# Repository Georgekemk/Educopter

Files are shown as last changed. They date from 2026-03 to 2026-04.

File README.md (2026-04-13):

<h1 align="center">EDUCOPTER</h1>

<p align="center">
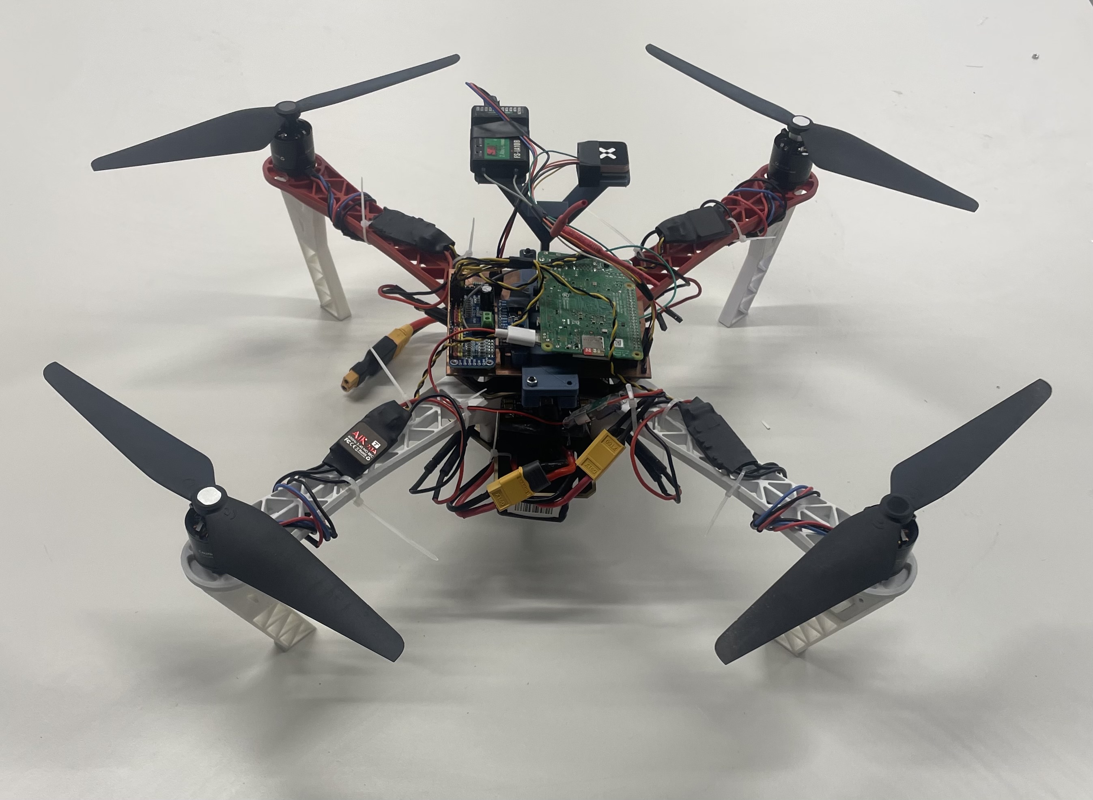
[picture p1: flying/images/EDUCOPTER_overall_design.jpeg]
  
</p>

Welcome to the **EDUCOPTER GitHub repository**.

This project has been developed based on the work of the **OBAL project**, which demonstrated that a Raspberry Pi can be used as the single flight computer for a custom ArduPilot flight controller. Thanks go to **Mohammad Hefny** for his contribution to custom Linux flight controller developement.

EDUCOPTER builds upon this foundation with the goal of creating a **simpler, highly replicable custom flight controller designed specifically for education and experimentation**.

---

# What is EDUCOPTER?

**EDUCOPTER** is a **minimal ArduPilot-compatible flight controller platform** designed to be easily reproduced by students, researchers, and hobbyists. Although this repository demonstrates its use on a quadcopter, the EDUCOPTER board can be used with any vehicle supported by ArduPilot, including rovers, fixed-wing aircraft, submarines, and multirotors.

Unlike many flight controller designs that prioritise performance or compactness, EDUCOPTER prioritises **simplicity and reproducibility**.

Key characteristics of the design include:

* A **Raspberry Pi–based Linux flight controller**
* A **single-sided PCB** for easy manufacturing
* Only **essential sensors and actuators** required to fly with ArduPilot
* ArduPilot source code changes for Linux porting
* Parameter and Service files to run alonside ArduPilot and MAVProxy
* A complete set of **documentation and instructions** allowing others to replicate the project from scratch with little experience in this area

The project demonstrates how a fully functional ArduPilot drone can be built with **minimal hardware complexity**, while still providing a powerful and flexible autopilot platform.

---

# Project Goals

The EDUCOPTER project aims to:

* Provide a **simple reference design** for a Linux-based ArduPilot drone
* Enable **students and educators** to build and understand a flight controller
* Demonstrate how **ArduPilot can run on custom hardware**
* Provide **clear instructions and documentation** for full system replication
* Present a guide for porting any custom Linux board design in ArduPilot firmware

---

# Repository Structure

This repository is organised into several sections to make it easy to understand and reproduce the project.

```
EDUCOPTER/
├── software/
├── hardware/
├── BOM/
├── flying/
├── testing/
├── Future Research/
```

Each section contains documentation and files required for a specific stage of the project. The future research section summarises the Linux board specific porting for ArduPilot, and gives some examples of future projects that can build from the EDUCOPTER platform.

---

# Software

The **software** section contains all code and configuration required to run ArduPilot on the EDUCOPTER flight controller.

This includes:

* Modified or configured ArduPilot code
* Supporting scripts and configuration files
* Instructions for installing and running the software on the Raspberry Pi

A detailed README inside this folder contains instructions for software implementation and **must be read**. It explains:

* Raspberry Pi setup and connection
* Linux Virtual Environment setup
* Compiling ArduPilot
* Configuring the EDUCOPTER board
* Connecting to ground control software
* Running the firmware and testing

```
software/
└── README.md
```

---

# Hardware

The **hardware** section explains how to construct the EDUCOPTER flight controller board.

This includes:

* PCB gerber files and images
* Circuit schematics
* Instructions for manufacturing the board
* Guidance for soldering components and assembling the hardware

The hardware README provides **step-by-step instructions** for building the EDUCOPTER board.

```
hardware/
└── README.md
```

---

# Bill of Materials (BOM)

The **BOM section** contains a complete list of components required to build both the EDUCOPTER flight controller and the final drone platform.

This includes:

* Electronic components used on the board
* Sensors and connectors
* External drone components such as motors, ESCs, frame, and power distribution board

These parts are included primarily for completeness; compatible alternatives may be used where appropriate.

```
BOM/
└── BOM.xlsx
```

---

## Testing the flight controller

The testing section documents the procedures used to verify correct operation of the EDUCOPTER flight controller before flight.

This section contains:

* Instructions for confirming SPI communication with the IMU
* Instructions for verifying I2C device detection for the barometer and PWM driver
* Instructions for testing UART connections for the GPS module and RC receiver

```
testing/
└── README.md
```
---

# Flying the Drone

The **flying** section demonstrates the final stage of the project.

This section contains:

* Images of the completed drone
* Instructions for integrating the EDUCOPTER board with a quadcopter design
* Instructions for performing the first flight

```
flying/
└── README.md
```

---

## Future Research

The future section then outlines possible extensions to the EDUCOPTER platform and identifies directions for further experimentation based on this architecture.

```
Future Research/
└── README.md
```

---

# Replicating the Project

This repository has been structured so that users can **follow the entire process from start to finish**, including:

1. Building the flight controller hardware
2. Installing and configuring the software
3. Assembling the drone platform
4. Performing system calibration and first flight

All necessary documentation is provided within the repository.

---

# Acknowledgements

This project builds upon the work of the **OBAL project** and the wider **ArduPilot community**.

Special thanks to **Mohammad Hefny** for his contributions to the OBAL platform and for enabling Linux-based flight controller development.

Also thanks go to **Oliver Vogt** for his supervision and guidance with this project.

---

# License

This project follows the licensing terms of the software and tools it builds upon. Please refer to the relevant directories for detailed licensing information.

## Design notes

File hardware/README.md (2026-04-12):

# EDUCOPTER Hardware Setup

This guide explains how to construct and assemble the **EDUCOPTER flight controller hardware**.  
It covers sensor connections, PCB manufacturing, soldering components, connecting peripherals, and powering the system.

The EDUCOPTER board has been intentionally designed to be **simple to manufacture and assemble**, using a **single-sided PCB** and only the sensors required for ArduPilot operation.

---

# 1. Sensor and Peripheral Connections

The EDUCOPTER board uses standard interfaces supported by **ArduPilot on Linux-based flight controllers**. Wherever possible, commonly used pin assignments have been used so that ArduPilot can detect and initialise sensors without extensive configuration.

A summary of hardware components and their communication methods is shown below. The black arrows represent physical connection on the PCB and the pink arrows represent connection via network port.

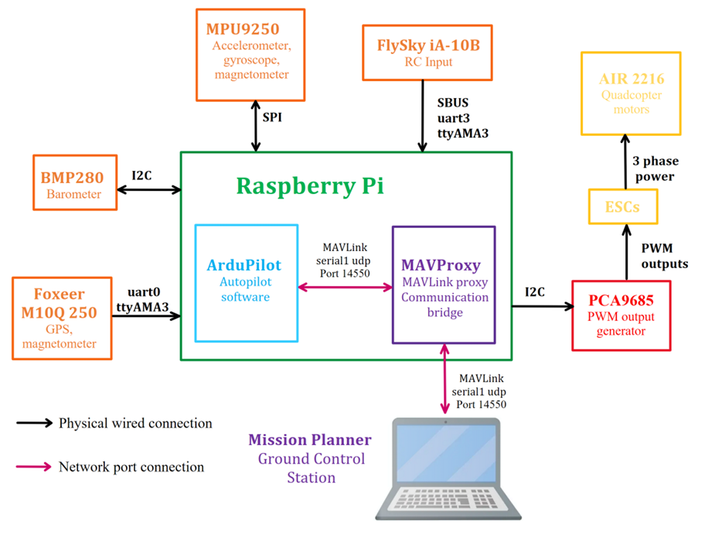
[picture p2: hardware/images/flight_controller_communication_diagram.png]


### Sensor Interface Overview

| Device | Interface | Purpose |
|---|---|---|
| IMU (MPU9250) | SPI | Attitude estimation (gyro + accelerometer) |
| Barometer | I2C | Altitude estimation |
| PCA9685 PWM driver | I2C | Motor PWM outputs |
| GPS module | UART | Position and velocity |
| RC Receiver (SBUS) | UART | Remote control input |

---

### SPI – IMU

The **IMU** is connected using the SPI interface. SPI provides fast and reliable communication required for inertial measurements.

SPI pins include:

- MOSI  
- MISO  
- SCLK  
- CS (chip select)

These are connected to the Raspberry Pi SPI bus using standard Linux ArduPilot mappings.

---

### I2C – Barometer BMP280 and PCA9685

Both the **barometer** and the **PCA9685 PWM driver** are connected using the **I2C bus**.

Advantages of I2C:

- Multiple devices share the same bus  
- Only two signal wires are required

---

### UART – GPS

The GPS module communicates using **UART serial communication**.

| GPS Pin | Connects To |
|---|---|
| TX | Raspberry Pi RX |
| RX | Raspberry Pi TX |
| VCC | 5V |
| GND | Ground |

**Important:**  
GPS **TX must connect to Pi RX**, and **GPS RX must connect to Pi TX**.

---

### UART – SBUS Receiver

The RC receiver uses the **SBUS protocol**, which transmits multiple RC channels over a serial connection.

SBUS can be used on many GPIO pins, but the configuration used in EDUCOPTER is UART0, using pins GPIO14 and 15.

Before use, the UART must be **enabled on the Raspberry Pi**.

The circuit schematic is shown below.

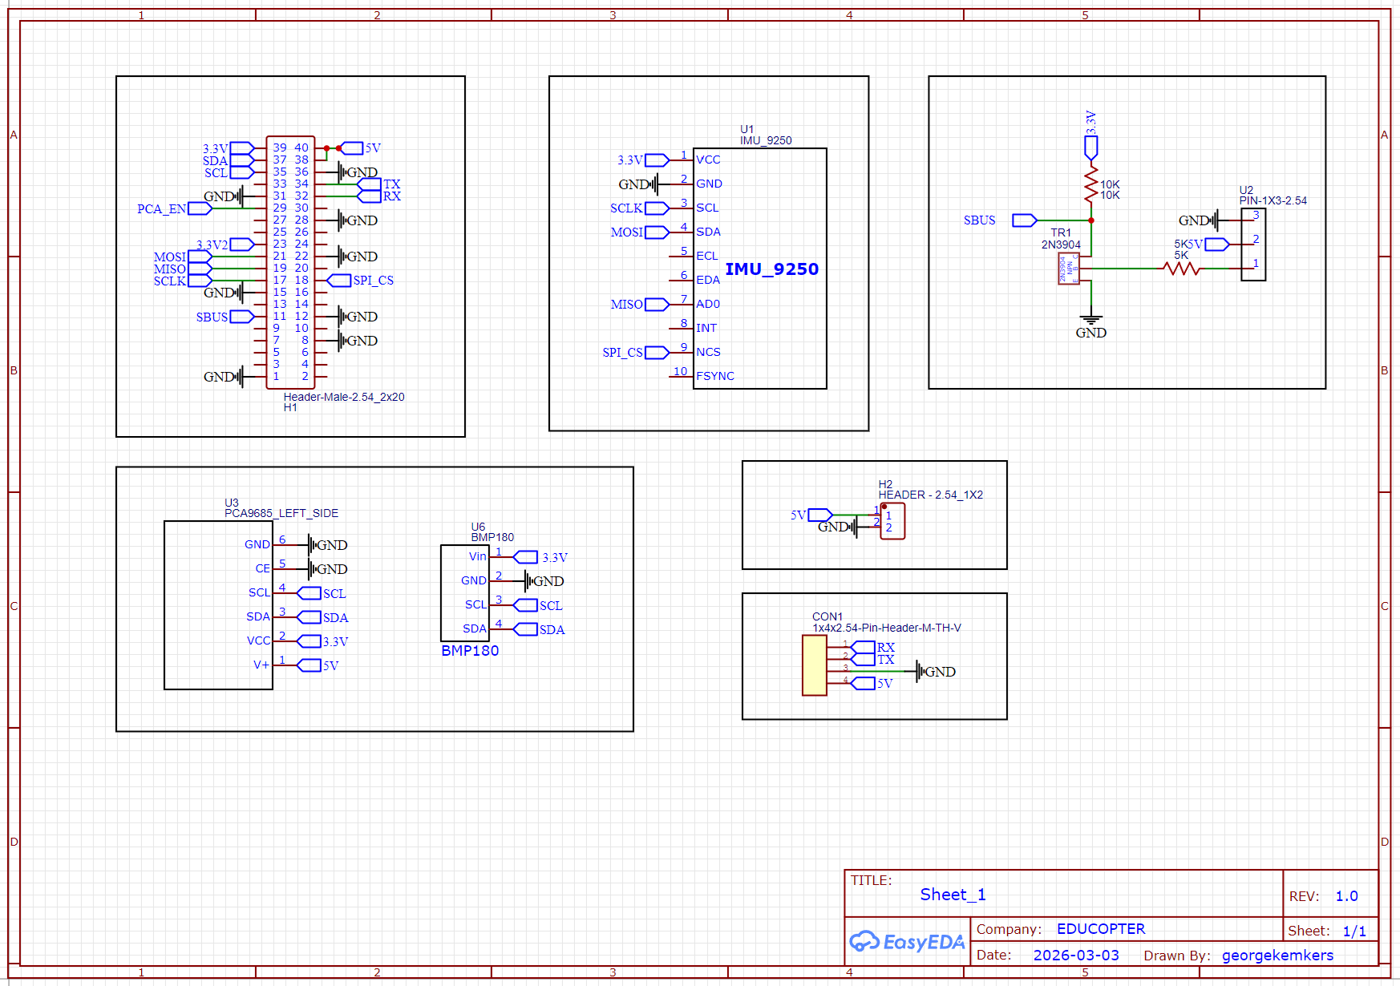
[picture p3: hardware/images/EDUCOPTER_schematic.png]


---

# 2. Build the SBUS Inversion Circuit

SBUS signals are **inverted**, whereas the Raspberry Pi UART expects **non-inverted serial data**.

To correct this, a **simple transistor inverter circuit** is used.

### Required Components

| Component | Value |
|---|---|
| NPN transistor | 2N3904 |
| Base resistor | 5 kΩ |
| Pull-up resistor | 10 kΩ |

### Circuit Operation

- SBUS signal enters the **base resistor**
- The transistor switches the signal
- The collector outputs a **non-inverted UART signal**
- The pull-up resistor ensures correct logic levels

This can be seen in the schematic in the box titled 'SBUS Inverter Circuit on UART3'

---

# 3. Manufacture the PCB

The EDUCOPTER PCB is designed to be **single sided**, making it suitable for **PCB milling machines**.

Advantages:

- Easier fabrication
- No vias required
- Suitable for educational environments

### PCB Structure

Two Gerber layers are used:

1. **Bottom copper layer (traces)**
2. **Top insulation layer**

All **traces and solder joints are on the bottom side** of the board, and the top side only electrically insulates the pins in case they touch the copper surface.

### Gerber Files

The gerber files are included in the hardware section of this repository.

---

### PCB Milling

The board used in this project was manufactured using a **Makera Carvera PCB milling machine**.

A **Standard Operating Procedure (SOP)** for using the Carvera can be found on Makera's website or youtube channel.

---

# 4. Solder the Components

Once the PCB has been manufactured, components must be soldered onto the board.

The EDUCOPTER PCB was designed with **approximately 0.35 mm trace spacing**, making it relatively managable for novice solderers.

### Required Tools

- Soldering iron  
- Solder  
- Tweezers  
- Flux (recommended)

All components should be soldered to the pads on the backside of the board, shown in the image below:

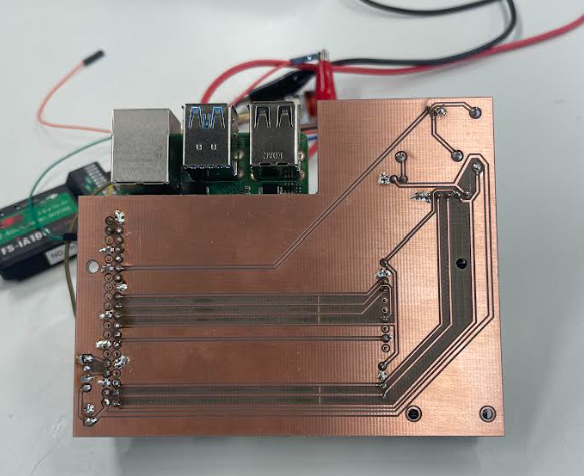
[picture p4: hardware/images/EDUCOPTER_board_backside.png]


---

# 5. Connect the RC Receiver and GPS

External peripherals connect via header pins.

---

### RC Receiver Connection

| Receiver Pin | Connect To |
|---|---|
| SBUS | SBUS input |
| 5V | 5V |
| GND | Ground |

The SBUS signal must pass through the **inversion circuit** before reaching the Pi UART.

---

### GPS Wiring

Correct wiring is essential.

| GPS Pin | Connect To |
|---|---|
| TX | Pi RX |
| RX | Pi TX |
| VCC | 5V |
| GND | Ground |

---

# 6. Power the Circuit

The EDUCOPTER board can be powered in two ways.

---

### Method 1 – PCB Power Pins

The board includes **dedicated 5V input pins**, shown in the 5V 3A Power input box in the circuit schematic.

Connect these to a 5V DC power supply from a regulated power source.

### Method 2 – Raspberry Pi USB-C

The board can also be powered using the Raspberry Pi **USB-C power input**, which is the primary method used for this design. A DC--DC buck converter with a usbc connector on the end is included in the BOM, and details of how to connect this are included in the 'flying' section of this repository.

---

# 7. Final Hardware Checklist

Before powering the board:

✔ Check for solder bridges  
✔ Confirm correct sensor orientation   
✔ Ensure GPS TX/RX wiring is correct  
✔ Confirm correct power polarity  

The completed board is with the GPS and RC receiver units connected is shown below:

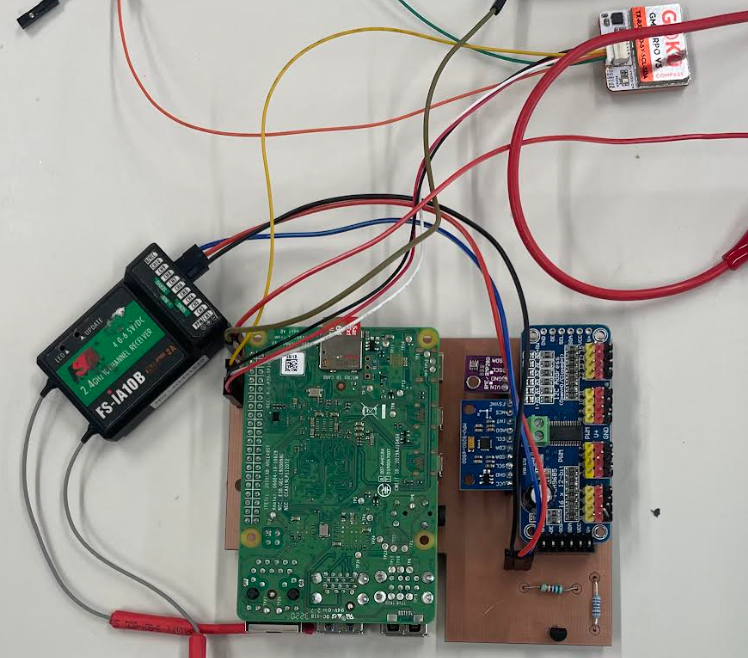
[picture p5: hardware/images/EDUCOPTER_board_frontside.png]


---

# Next Step

Once the hardware is assembled and verified, proceed to the **software setup instructions**:

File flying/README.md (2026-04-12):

# Assembling the EDUCOPTER Quadcopter

With the EDUCOPTER board successfully built and the EDUCOPTER binary installed along with MAVProxy and the system service files created, you're now ready to build the drone. Ensure the Raspberry Pi is connected to the EDUCOPTER board and follow these steps in order.

## 1. Installing the Holybro Power Distribution Board

Place the **Holybro PM07 power distribution board** inside the drone frame base plate.

Plug the four ESC power leads into the ports of the Holybro board.

Ensure:

- polarity is correct
- connections are secure
- cables are not under tension
- space is left above the board for mounting the EDUCOPTER controller

Insert image here

---

## 2. Mounting the EDUCOPTER Flight Controller

Fix the EDUCOPTER board to the top of the drone frame using a **3D printed mounting structure** designed for your frame geometry.

An example mounting structure is shown below.

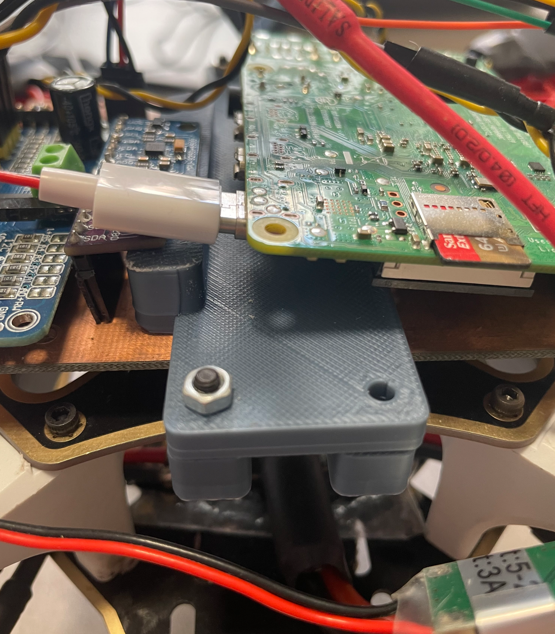
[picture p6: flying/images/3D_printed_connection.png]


Ensure:

- the board is rigidly mounted
- the IMU is firmly secured and can't wobble or vibrate
- the Raspberry Pi USB-C port remains accessible

Loose IMU mounting will cause incorrect attitude estimation during flight and control issues.

---

## 3. Connecting the GPS and RC Receiver

Connect the GPS module and RC receiver to the EDUCOPTER board.

Connections:

- GPS → 4 pin header with 5V, GND, RX, TX
- SBUS receiver → 3 pin header with GND, 5V, SBUS

Ensure that the cables connect to the correct corresponding pins by referring to the circuit schematic and gerber files. The GPS RX must connect to the Pi TX pin, and the GPS TX to the Pi RX.

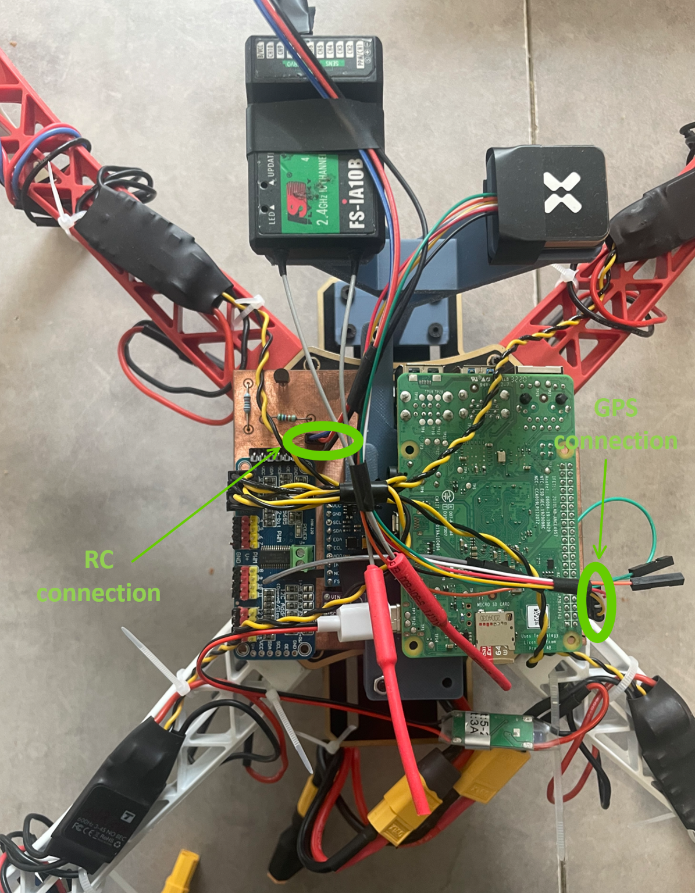
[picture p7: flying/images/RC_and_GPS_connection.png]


Use a structure to elevate the GPS and RC receiver above the board to minimise inteference to the GPS from power components and to increase the range of the receiver.

---

## 4. Connecting ESC Signal Outputs to the PCA9685

Attach the ESC signal wires to the signal and ground pins of the PCA9685.

ESC numbering follows the PCA9685 channel order from left to right:

- ESC 1 → Channel 0
- ESC 2 → Channel 1
- ESC 3 → Channel 2
- ESC 4 → Channel 3

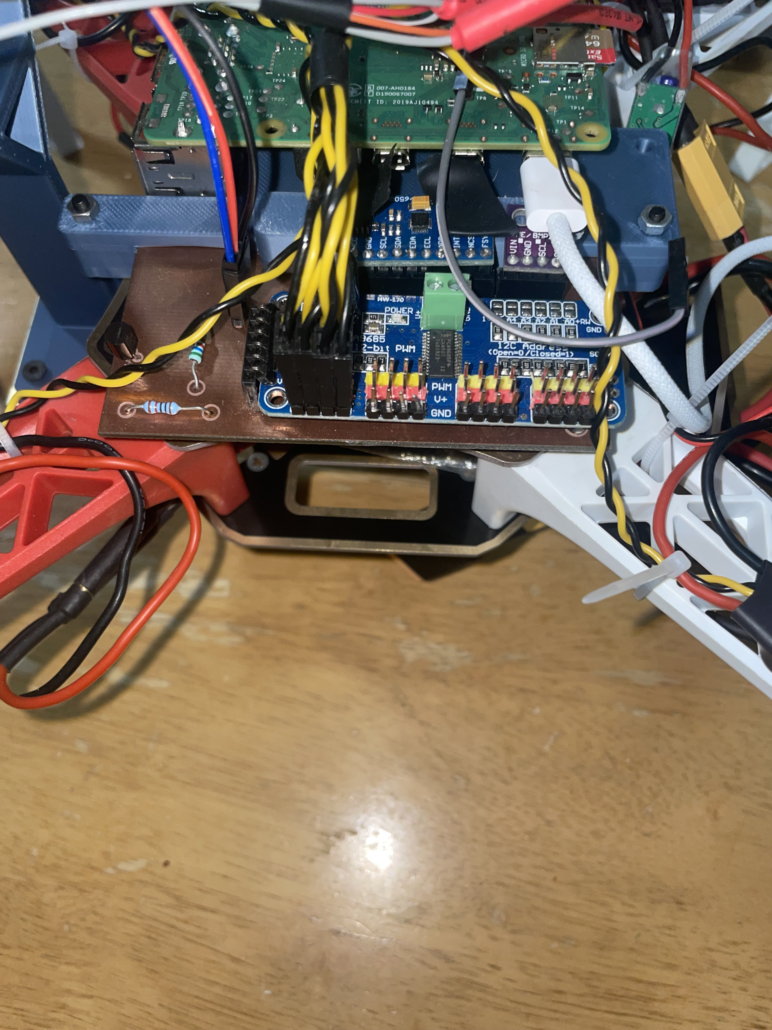
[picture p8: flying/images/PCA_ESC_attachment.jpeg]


The **QUAD-X motor configuration must be followed**.

Incorrect ordering will prevent stable flight.

---

## 5. Mounting the Motors

Attach the motors to the drone frame arms using the supplied nuts and bolts.

Once mounted, connect each motor to its ESC.

Do not attach propellers yet.

Motor rotation direction will be verified later during calibration.

---

## 6. Installing the Battery and Power Connections

Attach the battery to the underside of the drone frame. It is recommended to do this using a velcro mechanism so batteries can be easily substituted if needed, but any connect will suffice.

Connect the power splitter to the battery output, and connect the USBC to the Pi and the other connector to the power distribution board. 

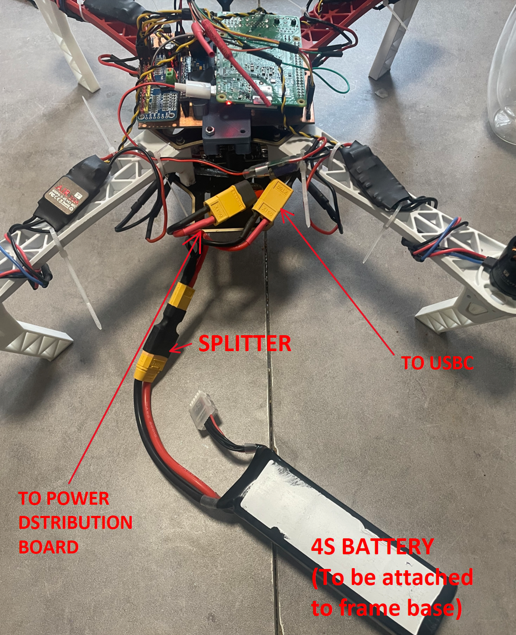
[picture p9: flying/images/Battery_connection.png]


The Pi should power on, the PCA will hold a solid red light and the GPS and RC receiver should light up. It is recommended at this point to ssh to the Pi so that it can be easily shutdown if errors occur.

---

## 7. Performing ArduPilot Calibration

Once assembly is complete, calibration can begin using Mission Planner.

Complete the following calibrations:

- accelerometer calibration
- compass calibration
- RC calibration

This can be done in the setup section of Mission Planner, where detailed instructions are located.

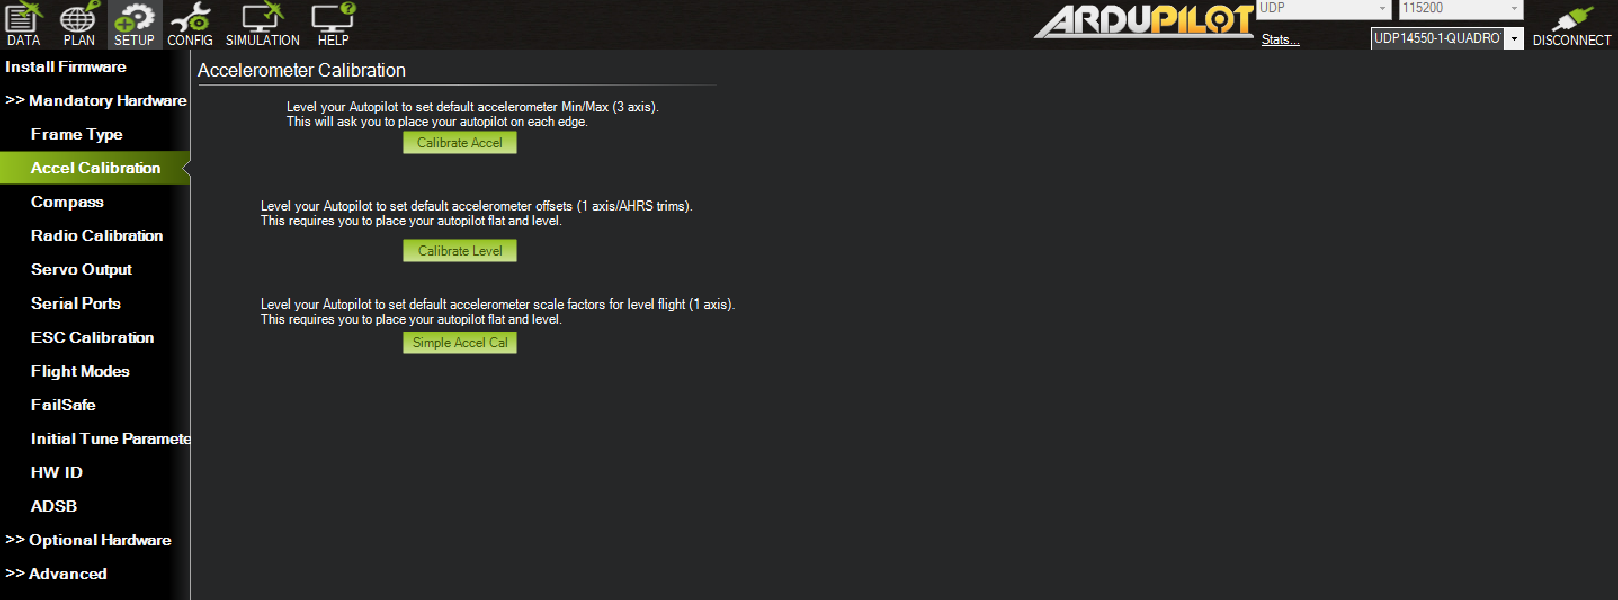
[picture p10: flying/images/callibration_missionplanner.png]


ESC calibration depends on ESC type. The standard ArduPilot ESC calibration process works for most ESCs but should be checked against manufacturer documentation before use.

---

## 8. Testing RC Outputs Before Flight

Ensure propellers are **not attached** before testing.

Arm the throttle using either:

the MAVProxy command

arm throttle

or by holding the RC throttle hard left for several seconds.

Test outputs by adjusting:

- throttle
- yaw
- pitch
- roll

Observe PWM outputs from the PCA9685 channels

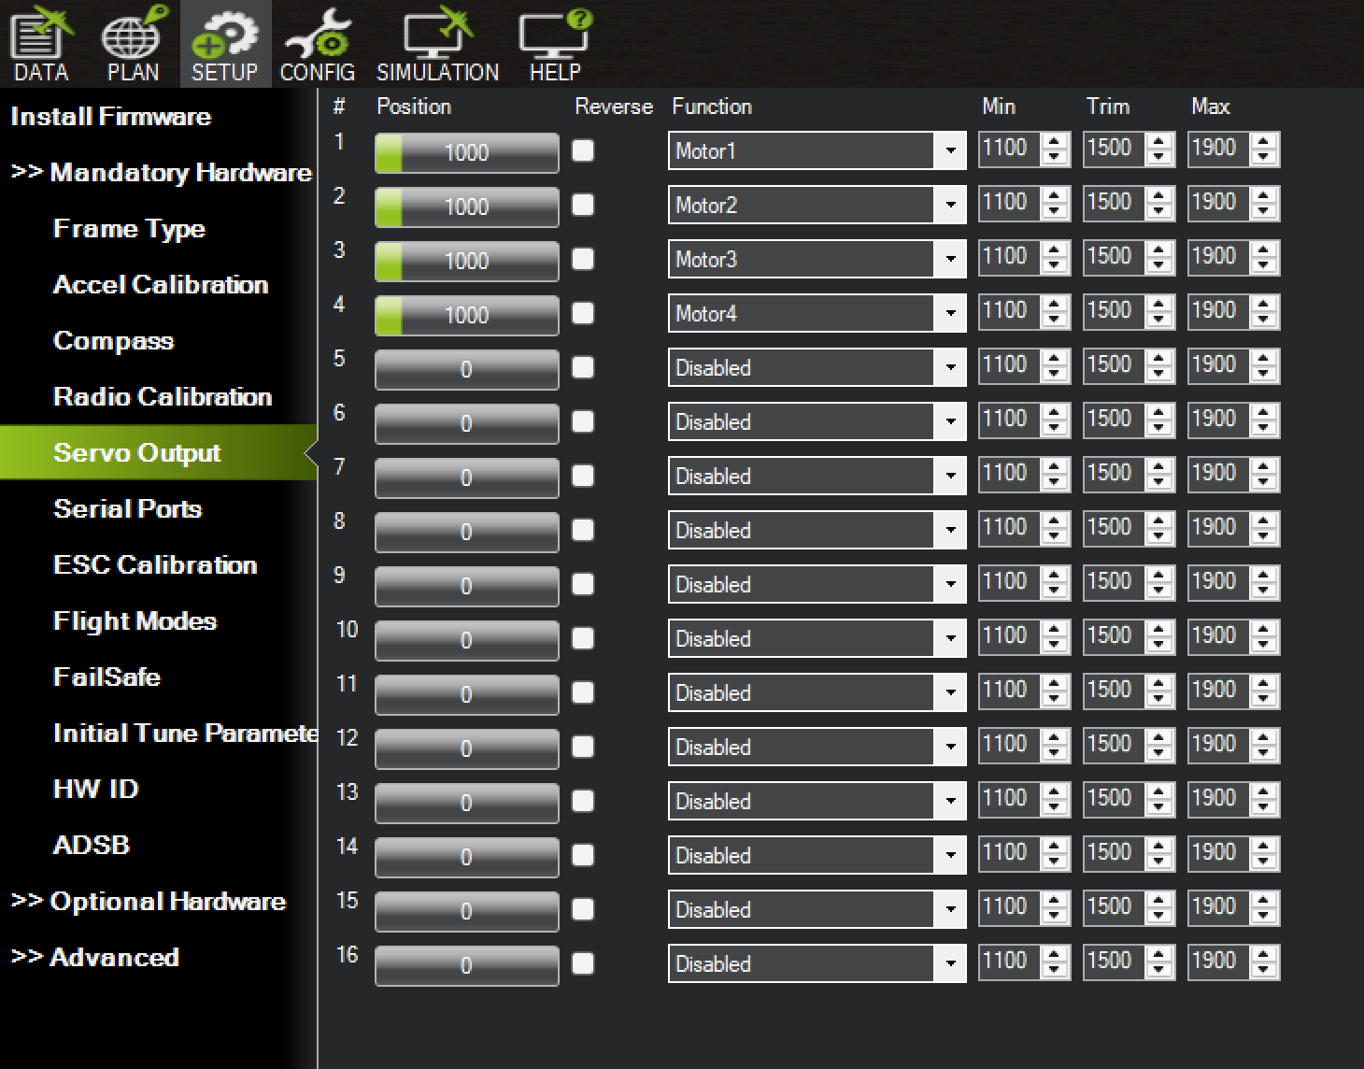
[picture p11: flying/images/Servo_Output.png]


---

## 9. Verifying Motor Rotation Direction

Using telemetry dash board in Mission Planner, tilt the drone in the x and y direction until the pitch changes. This can be used to find the forward direction of the drone. Alternatively, rotate the drone until the yaw reads 0 degrees. The front of the drone will now be facing North.

This will help to determine the correct motor rotation directions.

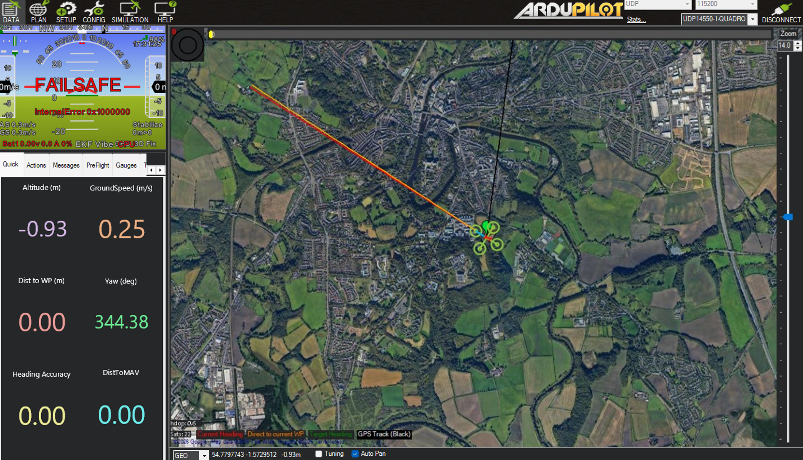
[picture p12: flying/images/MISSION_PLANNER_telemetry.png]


Use the Mission Planner motor test function to confirm correct motor rotation.

Expected QUAD-X rotation directions:

- front right → clockwise
- front left → counter-clockwise
- rear left → clockwise
- rear right → counter-clockwise

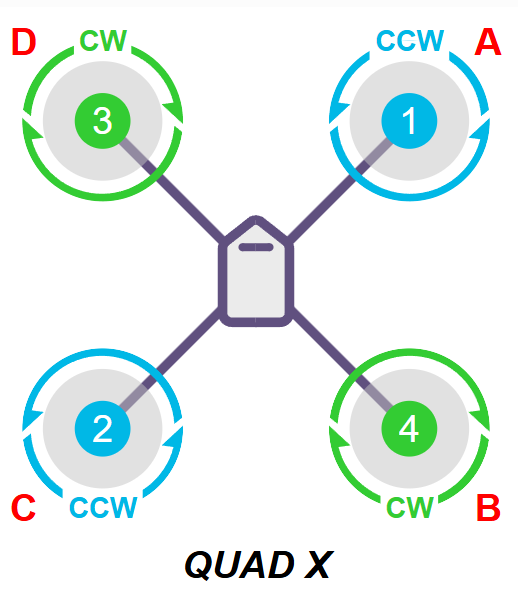
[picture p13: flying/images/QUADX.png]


If rotation is incorrect, swap any two ESC-motor wires.

---

## 10. First Flight

Once calibration and testing are complete, attach the propellers.

Move to an open outdoor space before attempting flight.

Before take-off confirm:

- battery secure
- GPS lock achieved
- transmitter connected
- failsafe configured
- correct flight mode selected

Set the initial flight mode to:

STABILIZE

Ensure compliance with local drone regulations before flying.

Happy flying!

## 11. Flight Results

Data from the flights was stored in a log file, the directory for which has already been assigned using **ardupilot.parm**.

The logs files from two seperate 30s flights were processed, and the plotted graphs are shown below:

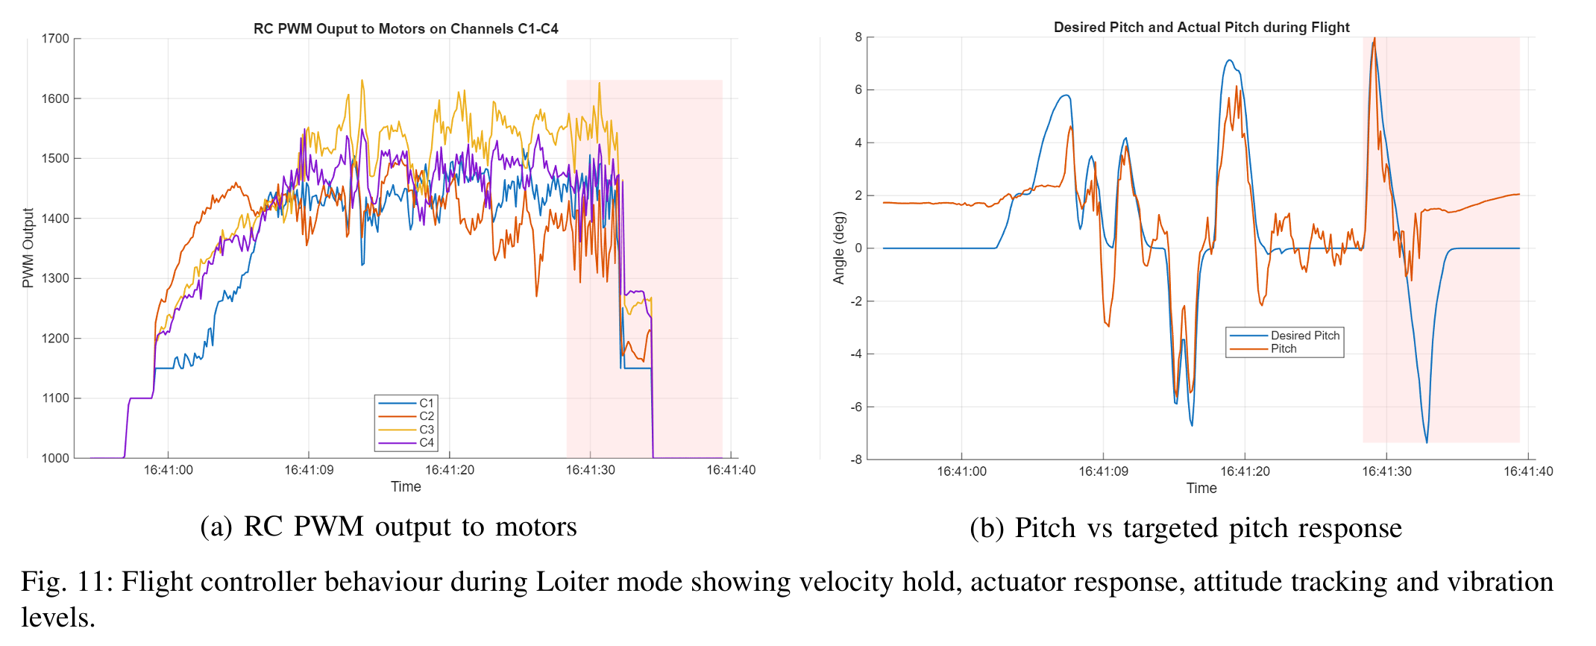
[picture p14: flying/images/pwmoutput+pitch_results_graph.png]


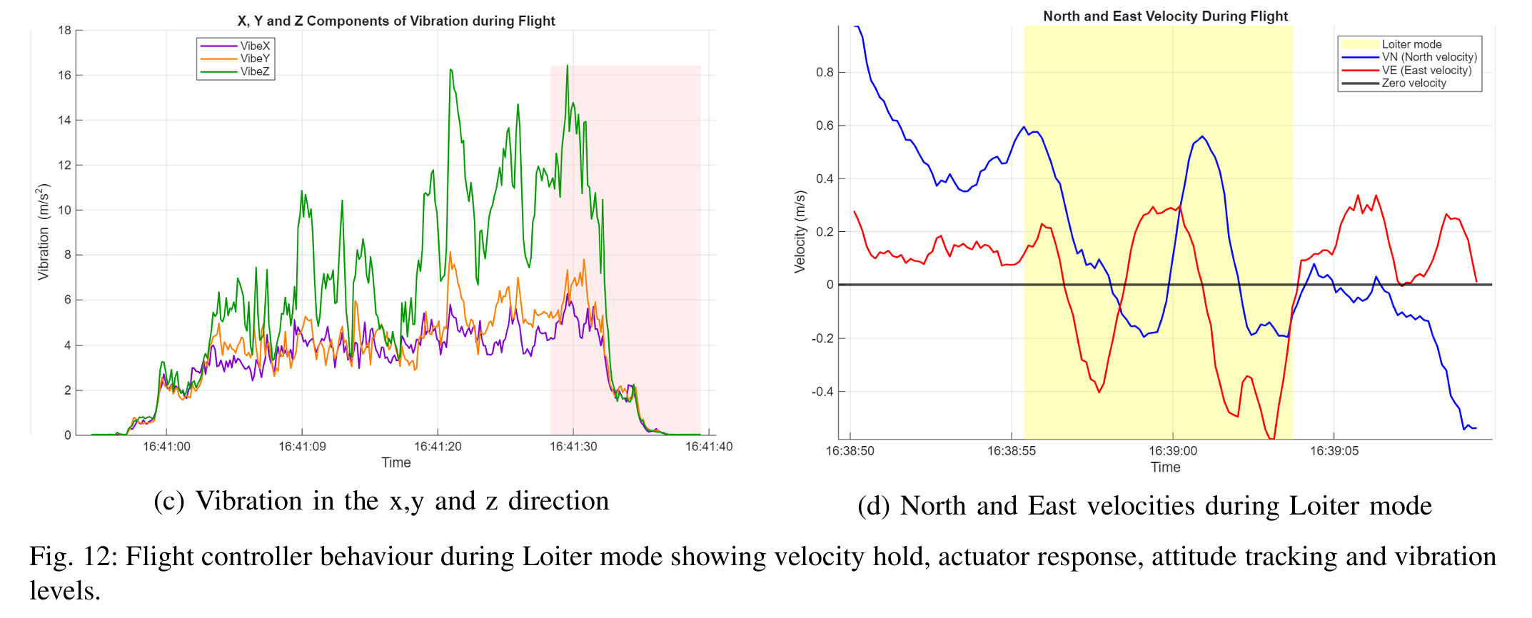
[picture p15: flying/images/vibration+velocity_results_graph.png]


The flying drone attached to a safety tether is shown below:

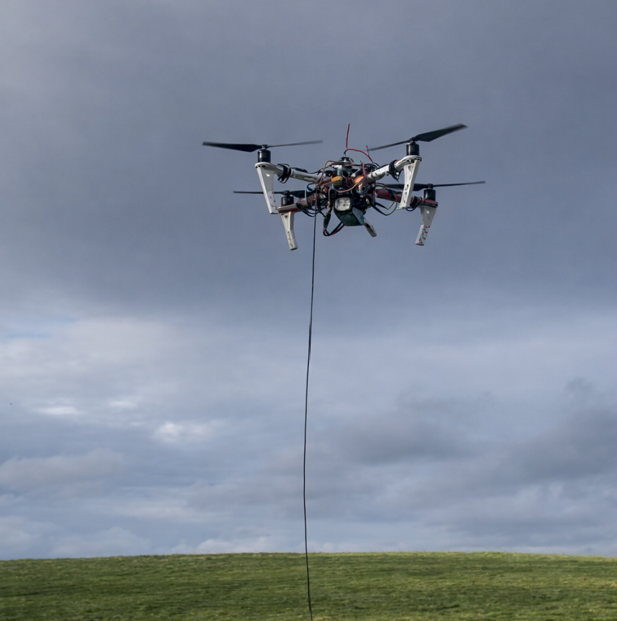
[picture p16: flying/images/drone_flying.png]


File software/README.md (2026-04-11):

# EDUCOPTER SOFTWARE – Running Educopter binary on a Raspberry Pi

This repository documents the software setup required to run **ArduPilot Educopter on a Raspberry Pi** using the custom **EDUCOPTER hardware configuration**.

It includes:

- Raspberry Pi OS installation
- ArduPilot source modifications for the EDUCOPTER board
- Building ArduPilot on a Linux VM
- Copying the build to the Raspberry Pi
- Downloading MAVProxy to the Raspberry Pi
- MAVLink communication with MAVProxy and Mission Planner
- System service configuration

The aim of this readme is to:
1. Allow the reader to directly replictae this project
2. Detail the steps that would enable the creation of a new Linux board

---

# Tips and Tricks

This repository was published in April 2026. Please be aware that ArduPilot may have changed board name definition locations for Linux since this publication. If you find these instructions aren't resulting in a correct binary build, I'd recommend using the grep function in Linux terminal to search for other Linux boards. This way you can see which files and corresponding sections to edit. For example, in your ardupilot directory:

`grep -rn "_OBAL" libraries/`

or

`grep -rn "NAVIO2" libraries/`

Then observe which files these definitions are located in and add your board definitions if necessary.

---

# 1. Preparing the Raspberry Pi

## Install Raspberry Pi OS

Download **Raspberry Pi Imager** from the Raspberry Pi website to your laptop.

Install the following image:

**Raspberry Pi OS Lite (32-bit)**

The Lite version is recommended because:

- it is lightweight
- it reduces CPU usage
- it avoids unnecessary desktop processes that can slow the ArduPilot main loop

Insert an SD card into a reader and flash the image using the imager.

---

## Naming the Pi

For simplicity and to avoid directory errors in the Pi's terminal, set the following details for the Raspberry Pi

- **Name** 'pi'
- **Password** 'password'

## Enable WiFi using the laptop hotspot

Ensuring the Pi connects to your laptop hotspot makes ssh to Pi possible with the laptop connected to any network

First, change your hotspot settings on your laptop to 2.4GHz band. This is the only band width the Pi can connect to and will cause countless hours of stress and confusement if left at 5GHz!

To allow the Pi to connect to the laptop hotspot during first boot:

1. In Raspberry Pi Imager open **Advanced Options**
2. Enable **WiFi configuration**
3. Enter the hotspot credentials

Example:

- **SSID Name:** `LaptopSSID_name`
- **Password:** `**********`
- **Country:** `GB`

---

## 2. First boot

Insert the SD card into the Raspberry Pi and power it on using the 5V usbc port.

Connect via SSH from your Linux virtual machine's terminal. Find the Pi's IP address by looking in your hotspot's connected devices and enter the following:

`ssh pi@<pi_ip_address>`

e.g.

`ssh pi@192.168.137.119`

Update packages:

`sudo apt update`

`sudo apt upgrade`

---

# 3. Enabling SPI, I2C and UART on the Raspberry Pi

In order to enable the Pi's external pins, run this command in the terminal:

`sudo raspi-config`

Navigate to Interface Options →

Then select the following:
1. SPI → Enable
2. I2C → Enable
3. Serial Port:
  a. Login shell over serial → Disable
  b. Serial hardware → Enable

With these steps completed, reboot the Pi using

`sudo reboot`

---

# 4. Preparing the Build Environment (Linux VM)

ArduPilot is built on a **Linux virtual machine** rather than directly on the Raspberry Pi. This allows faster compilation and avoids installing unnecessary development tools on the Pi, whilst enabling an easy ssh connection. Alternatively ssh can be performed using VSCode.

I used Oracle VirtualBox box to run a version of Ubuntu but you can use any VM that you prefer. The guide for to install Ubuntu on Oracle VirtualBox can be found here:
https://ubuntu.com/tutorials/how-to-run-ubuntu-desktop-on-a-virtual-machine-using-virtualbox

As a visual aid, the general overview of the workflow on the VM and the Raspberry Pi is shown by the diagram below.

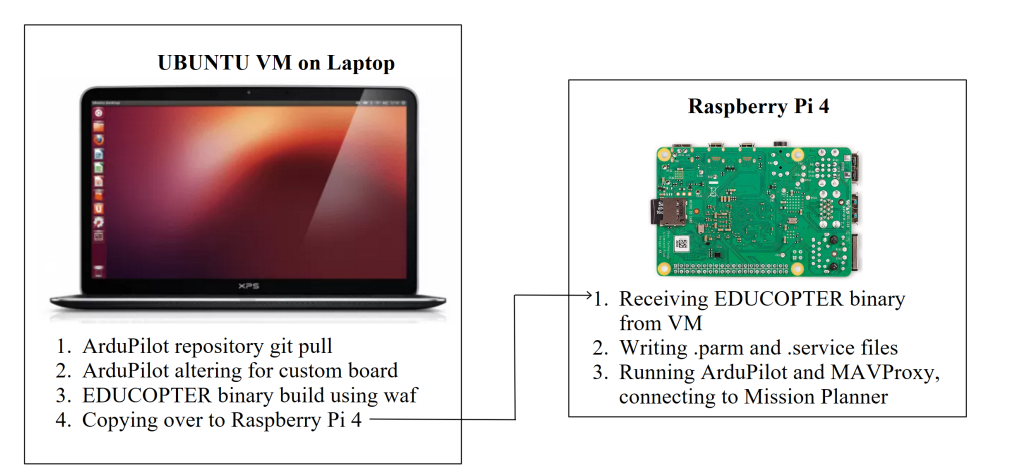
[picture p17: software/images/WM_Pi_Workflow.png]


---

# 5. Clone the ArduPilot source code

**IMPORTANT** Clone the ardupilot repository on your Linux virtual machine. When you eventually build the board subtype using waf, this will save time and also keeps the workflow organised. Of course you can clone it straight to the Pi, but building the binary will take approximately 45 minutes on a Pi 5. On a Pi zero, the build would likely take days!

In a terminal on the VM, clone the repository:

`git clone https://github.com/ArduPilot/ardupilot.git`

Enter the directory:

`cd ~/ardupilot`

Initialise the submodules:

`git submodule update --init --recursive`

---

# 6. Adding the EDUCOPTER Hardware Definition

Create the directory:

`ardupilot/libraries/AP_HAL_Linux/hwdef/EDUCOPTER`

You can do this using the command:

`sudo nano ardupilot/libraries/AP_HAL_Linux/hwdef/EDUCOPTER`

Copy the `hwdef.dat` file from this repository into that directory.

This file defines:

- Sensors
- Communication methods (I2C, SPI)
- GPIO mappings
- Board subtype
- Log file directories

used by the EDUCOPTER board.

---

# 7. Required Source Code Modifications

A small number of changes must be made to ArduPilot's Linux HAL so the EDUCOPTER board is recognised correctly.

These modifications allow the system to:

- recognise the new board subtype
- enable Raspberry Pi specific utilities
- configure flight sensors
- configure RC input handling (SBUS)

Only the relevant lines should be changed so that the setup remains easier to maintain when ArduPilot updates.

---

## Modify `AP_HAL_Boards.h`

File:

`libraries/AP_HAL/AP_HAL_Boards.h`

Add a new board subtype definition for EDUCOPTER.

### Why this is needed

This allows ArduPilot to distinguish the board from other Linux targets such as Navio or BeagleBone.

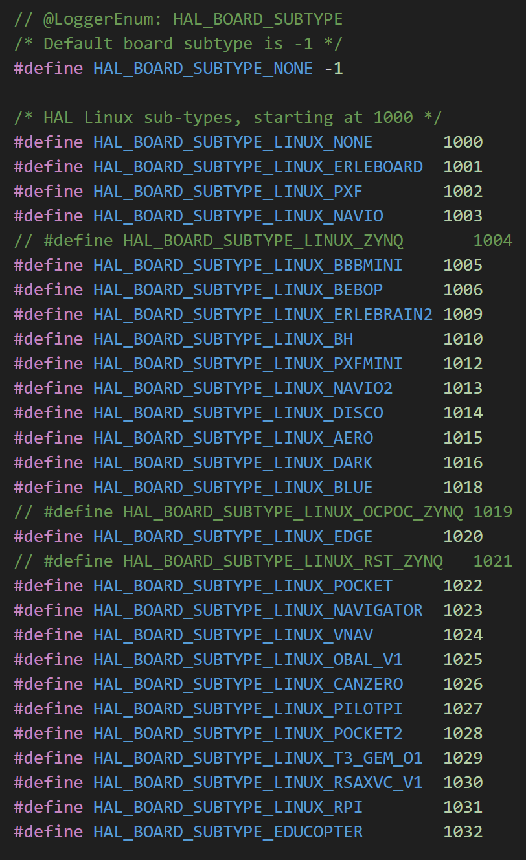
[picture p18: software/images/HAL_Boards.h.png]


---

## Modify `HAL_Linux_Class.cpp`

File:

`libraries/AP_HAL_Linux/HAL_Linux_Class.cpp`

This file:
- Defines board subtype
-  Maps RC Input Protocol
-  Maps RC Output (signal to the ESCs)

The modification steps are as follows:

1. Add EDUCOPTER board subtype definition
   
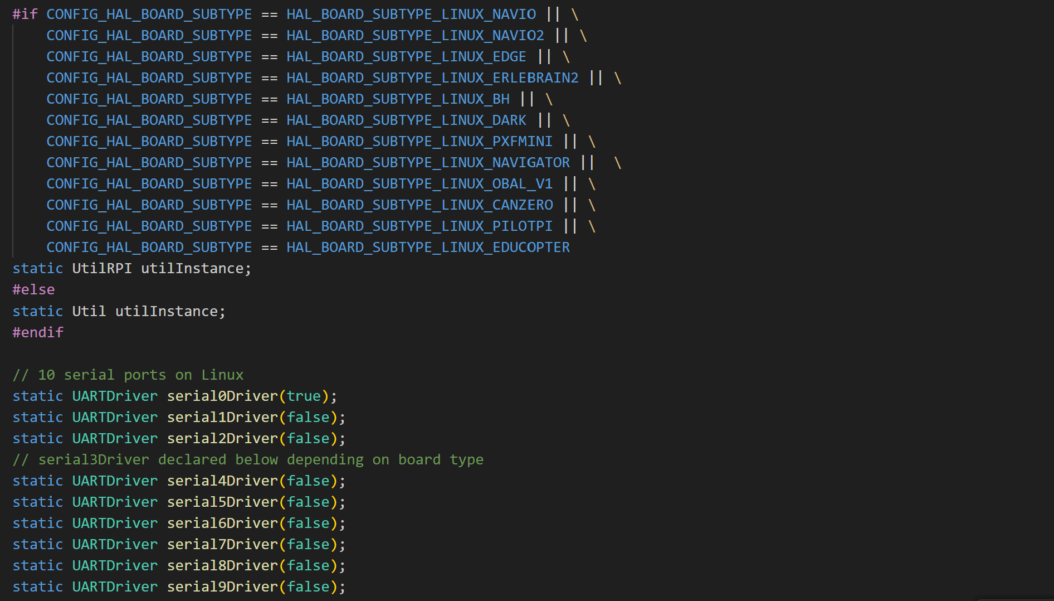
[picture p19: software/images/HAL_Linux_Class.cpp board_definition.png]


2. Add EDUCOPTER RCInputProtocols definition

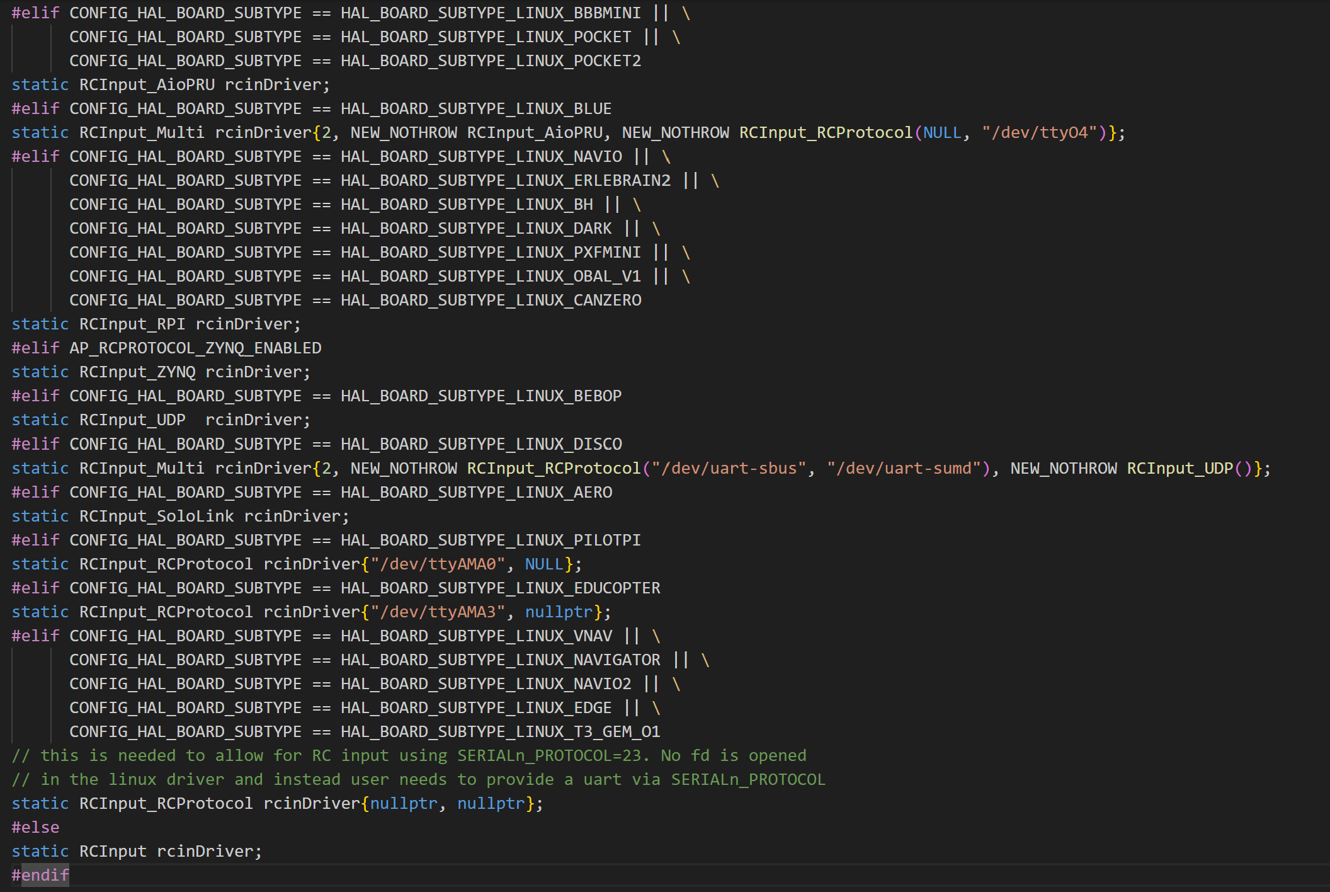
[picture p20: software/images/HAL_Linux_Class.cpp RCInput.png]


But what exactly does the line do?

static RCInput_RCProtocol rcinDriver{"/dev/ttyAMA3", nullptr};

This line instantiates the RCInput_RCProtocol driver, which is responsible for reading RC receiver data from a Linux serial device and passing it to ArduPilot’s AP_RCProtocol decoder. This decoder can interpret multiple RC protocols such as iBUS, SBUS and CRSF.

For the EDUCOPTER board, the receiver is connected to the Raspberry Pi UART exposed as /dev/ttyAMA3. The second constructor argument is set to nullptr, indicating that no secondary 115200-baud RC input device is used.

On the Raspberry Pi, /dev/ttyAMA3 corresponds to the UART mapped to GPIO4 and GPIO5, which is used to receive the serial RC data from the receiver. The configuration of this UART is discussed in greater detail in Step X of this README.

3. Add EDUCOPTER RCOutput definition

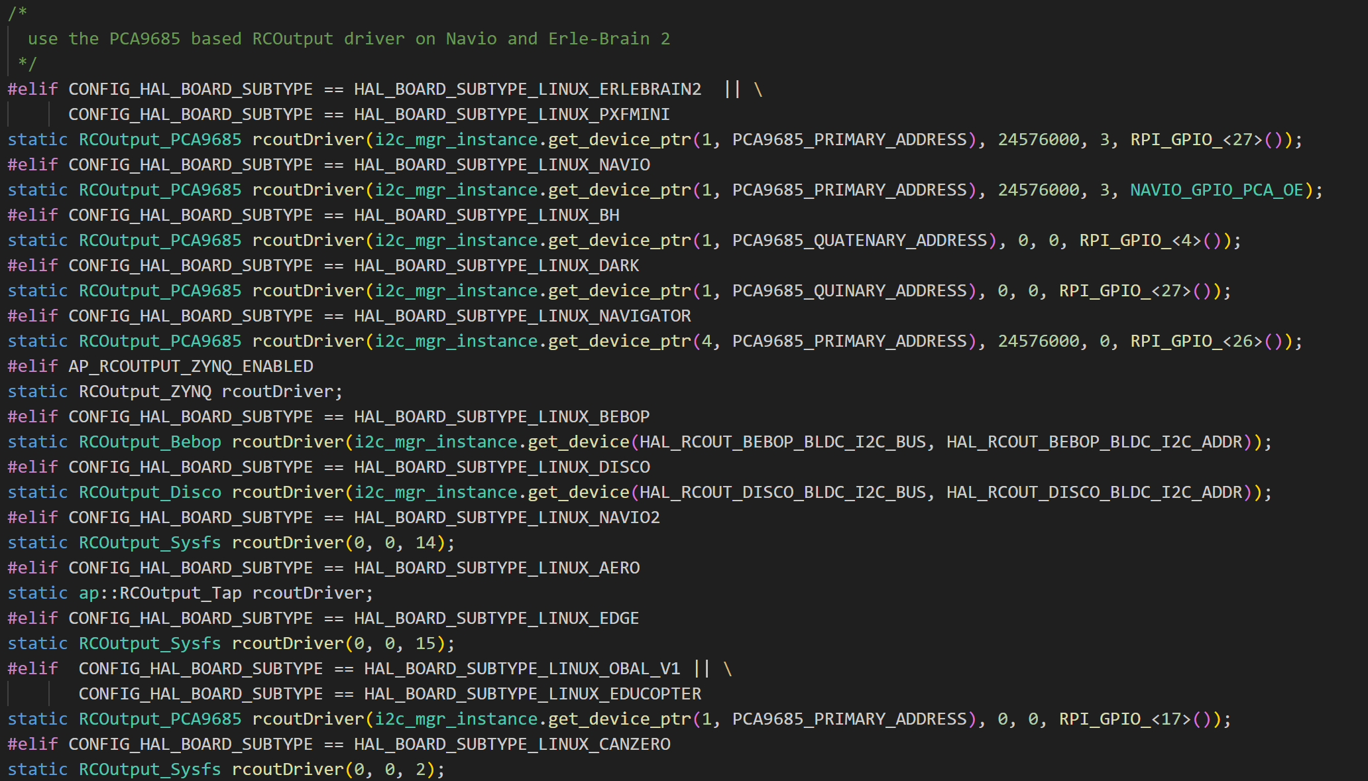
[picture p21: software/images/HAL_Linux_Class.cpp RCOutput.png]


static RCOutput_PCA9685 rcoutDriver(i2c_mgr_instance.get_device_ptr(1, PCA9685_PRIMARY_ADDRESS), 0, 0, RPI_GPIO_<17>());

This line was written in the OBAL project and has been kept. EDUCOPTER uses the PCA9685 to generate PWM signals to the ESCs, in turn driving the motors. 'RPI_GPIO_<17>()' corresponds to the pin that connects the PCA enable switch. EDUCOPTER has this line grounded to reduce complexity, but the line has been left in for educational purposes

---

## Modify `Util_RPI.cpp`

File:

`libraries/AP_HAL_Linux/Util_RPI.cpp`

Add the EDUCOPTER subtype to the Raspberry Pi utility functions.

### Why this is needed

This allows the board to use Raspberry Pi specific functionality such as:

- GPIO handling
- CPU detection
- system utilities

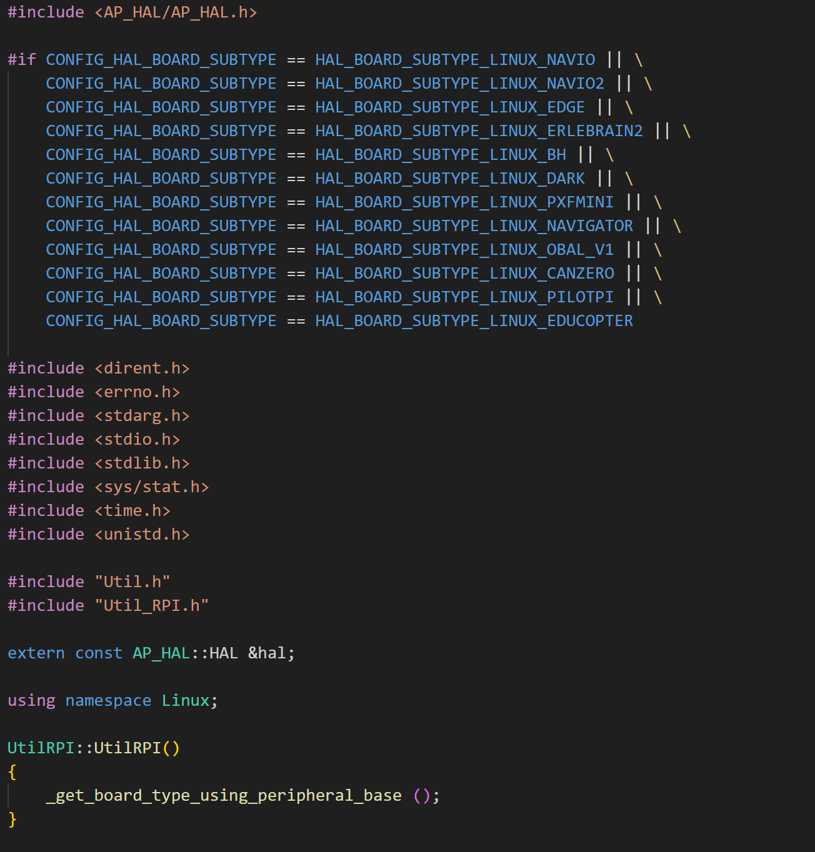
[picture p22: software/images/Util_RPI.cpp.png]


---

## Modify `RCInput_RCProtocol.cpp`

File:

`libraries/AP_HAL_Linux/RCInput_RCProtocol.cpp`

You must also include the board definition in the .cpp and .h file to use RCInput_Protocol

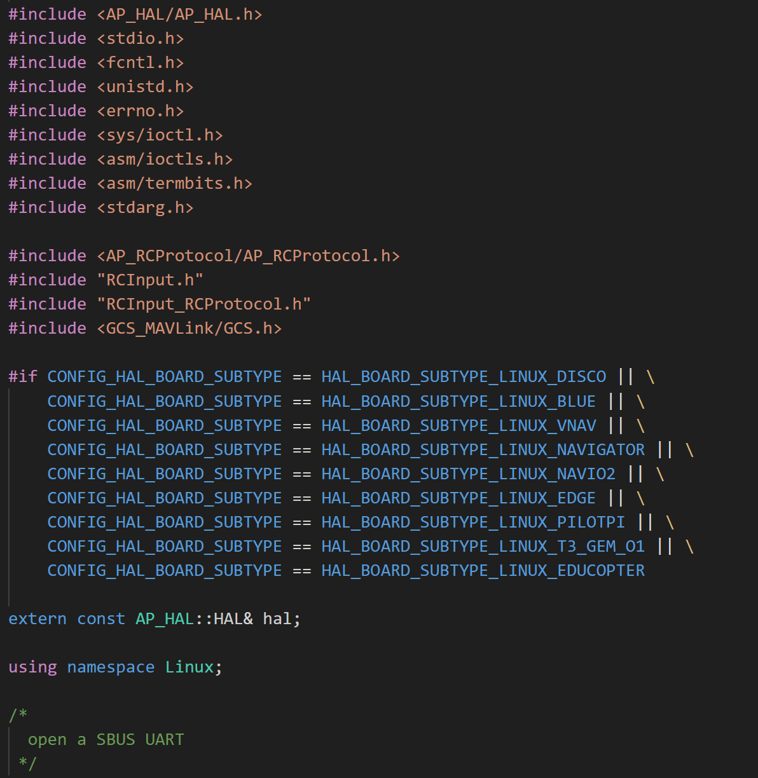
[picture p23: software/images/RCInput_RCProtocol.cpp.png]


---

## Modify `RCInput_RCProtocol.h`

File:

`libraries/AP_HAL_Linux/RCInput_RCProtocol.h`

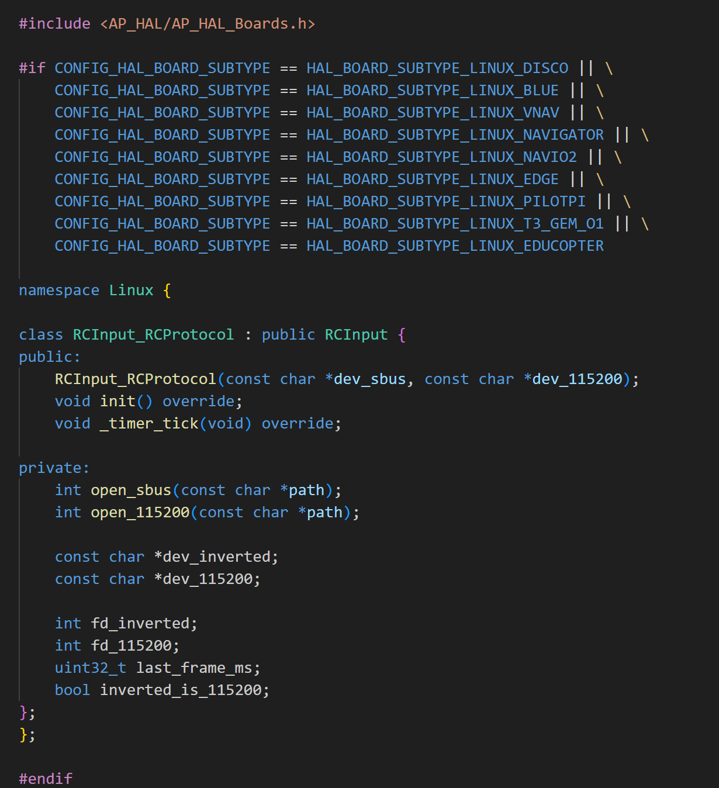
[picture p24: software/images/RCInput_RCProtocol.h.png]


---

# 8. Building ArduPilot

**First** make sure that you have saved all changes in the source code, and that you've created hwdef.dat in the correct directory.

Then from inside the ArduPilot directory, with the virtual environment activated, wipe any previous builds and configure the build for the EDUCOPTER board:

`./waf distclean`

`./waf configure --board=EDUCOPTER`

Then build ArduCopter:

`./waf copter`

If successful, the binary will appear at:

`build/EDUCOPTER/bin/arducopter`

### Why a virtual environment is used

Using a dedicated Python environment avoids conflicts with system Python packages and keeps the build reproducible.

**NOTE**
To build a custom board, replace EDUCOPTER with the name of your board defined in the source code edits. Remember to be be case sensitive!

---

# 9. Copying the Binary to the Raspberry Pi

First, power on the Pi and connect to it via ssh as directed in step 2.

On the Virtual Machine, use `scp` to transfer the binary to the Raspberry Pi:

`scp build/EDUCOPTER/bin/arducopter pi@<pi_IP_address>:/home/pi/`

The binary is now ready on the Pi.

---

# 10. Creating the Python Build Environment

ArduPilot uses **Python tools during compilation**, so the build should be done inside a virtual environment.

Create a virtual environment named `ardupilot-venv`:

`python3 -m venv ardupilot-venv`

Activate it:

`source ardupilot-venv/bin/activate`

Install the required Python packages:

`pip install future`

`pip install empy`

`pip install pyserial`

`pip install pyyaml`

`pip install numpy`

If additional ArduPilot Python dependencies are required on your machine, install them into the same environment.

This part of the process can be quite painful. Syntax errors are common and as ArduPilot continues to develop its code, new dependencies will likely appear. Terminal should prompt you to download the correcr packages when you go to build EDUCOPTER or your own custom Linux board.

# 11. Installing MAVProxy on the Raspberry Pi

MAVProxy is a python application and is used for MAVLink communication with the arducopter binary and a ground control station like Mission Planner. It is not strictly necessary but is helpful for streamlining communication and debugging. I would highly recommend using it for EDUCOPTER and any other board you may build.

Create a Python virtual environment on the Pi named `mavproxy-venv`:

`python3 -m venv mavproxy-venv`

Activate it:

`source mavproxy-venv/bin/activate`

Install MAVProxy:

`pip install MAVProxy`

If required, install any supporting Python packages into the same environment.

Ardupilot documentation lists the modules usually required, but like the previous python package downloads performed in the venv inside the Linux VM, this process can be tricky and demands patience.

---

# 12. MAVLink Communication

ArduPilot sends MAVLink telemetry to MAVProxy and Mission Planner over UDP or TCP. In this project UDP is used because it provides a lightweight, low-latency connection suitable for real-time telemetry streaming. You dob't need to run any of this sections code in the Pis terminal; it purely exists for educational purposes.

Example configuration in `ardupilot.service`:

`--serial1 udp:0.0.0.0:14550`

This allows MAVProxy or Mission Planner to connect.

Example MAVProxy command:

`mavproxy.py --master=udp:127.0.0.1:14550`

---

# 13. Systemd Service

The repository includes an example `ardupilot.service` file.

Copy it to:

`/etc/systemd/system/`

You should now have the directory:

`/etc/systemd/system/ardupilot.service`

Enable the service:

`sudo systemctl enable ardupilot`

Start it:

`sudo systemctl start ardupilot`

Check the status:

`sudo systemctl status ardupilot`

**NOTE** If you make any changes to the .service file after originally writing it, you must reload the file before using it:

`sudo systemctl daemon-reload`

---

# 14. Parameter File

The repository also includes an `ardupilot.parm` file.

Copy it to the location expected by the binary, for example:

`/home/pi/ardupilot.parm`

This file contains the startup parameters required for the EDUCOPTER configuration, including telemetry and GPS serial settings.

# 15. Download Mission Planner on your PC

Click the ArduPilot documentation link below to download Mission Planner for your Operating System. Don't do this on your Linux VW, download it straight onto your laptop.

https://ardupilot.org/planner/docs/mission-planner-installation.html

Once downloaded, follow the steps until you reach the main page and leave it for now.

# 16. Running ardupilot and MAVProxy

If you've made it to this step, congratulations! You're ready to run your built binary on the Pi and connect it via MAVProxy to Mission Planner. Follow these steps in order:

1. Check that ardupilot is running:

`sudo systemctl status ardupilot`

If it isn't, restart it and check the status again:

`sudo systemctl restart ardupilot`
`sudo systemctl status ardupilot`

2. Run MAVProxy and connect to ardupilot and Mission Planner:

`mavproxy.py --master=udp:127.0.0.1:14550 --out=udp:<laptop_IP_address>:14550`

Make sure to insert the IP address of whatever device is running Mission Planner. For example:

`mavproxy.py --master=udp:127.0.0.1:14550 --out=udp:192.168.137.1:14550`

Whilst the Pi isn't connected to the physical board, you will get Barometer erros and likely lots of binary symbols displaying on your screen. This is normal and will go away when the board is connected.

3. On your laptop, open Mission Planner and connect to MAVProxy via UDP port 14550. The connect icon is on the top right of the screen.

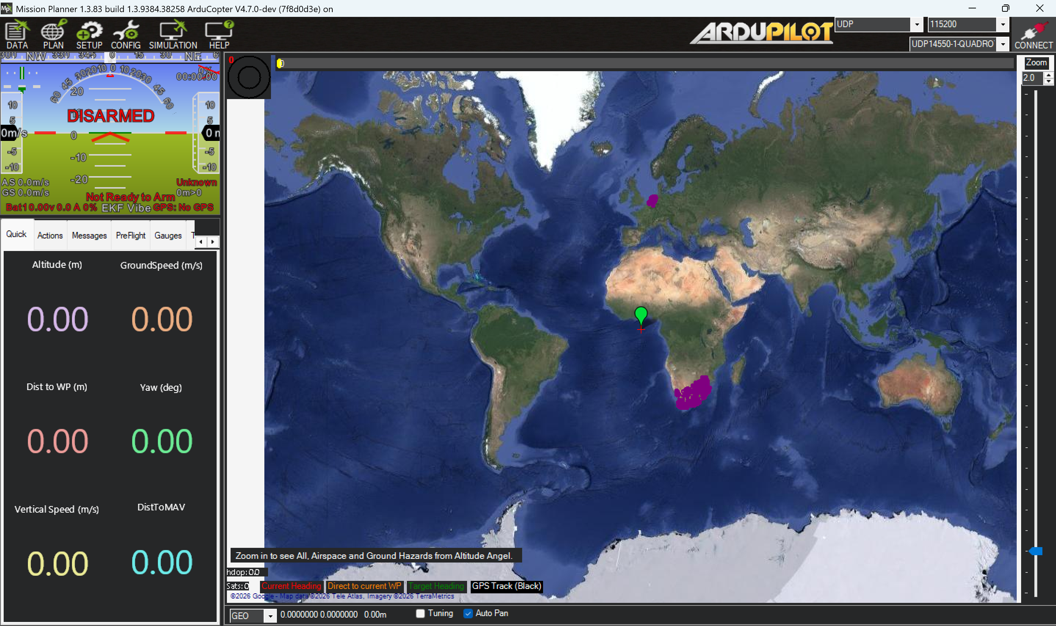
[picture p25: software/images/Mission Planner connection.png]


Without the Pi connected to the board, no telemetry data will appear in the Mission Planner dashboard. In messages, you will see MAVProxy displaying the same errors you saw previously.

But congratulations! You've set up the software for EDUCOPTER and you're ready to connect your board!

This next step is detailed in the README.md document located in the 'flying' folder.

---

# Notes

This repository documents the **software setup only**. Hardware wiring, PCB layout, power distribution, and sensor integration are documented in the README.md in the hardware section of this repository.

Where ArduPilot source files must be edited, only the relevant changes should be documented rather than copying entire upstream files. This makes the instructions more robust to future ArduPilot updates.

All images in these instructions are located in /software/images for reference.

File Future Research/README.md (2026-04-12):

# Research Presentation and ideas for future designs

This project was developed not only as a working ArduPilot controller for Planes, Copters, Rover and Subs, but as a **research platform demonstrating how ArduPilot can be ported to a minimal Linux-based hardware architecture**. A key objective of EDUCOPTER is to make the internal structure of the ArduPilot Linux Hardware Abstraction Layer (HAL) easier to understand and extend for educational use.

Two architecture diagrams are included within this repository to support this goal.

## Linux porting software architecture



This diagram presents the **Linux porting software architecture**. Files highlighted in green require editing for this specific Linux board subtype, and the diagram shows how the vehicle firmware interacts with the Linux HAL and how SPI, I2C and UART sensor drivers are integrated into the ArduPilot build system using `waf`.

1. **AP_HAL_Boards.h** -> Defines Linux board subtype name
2. **EDUCOPTER/hwdef.dat** -> Hardware defintion file defining IMU, Baro, Compass and their communication types e.g. SPI, I2C
3. **AP_Linux_Class.cpp** -> Defines RC Input and Output devices and methods, like PCA on I2C and SBUS over UART
4. **RCInput_RCProtocol** -> Additional file with SBUS definitions

These Linux Hardware Abstraction Layer (HAL) files are then processed by waf using the build instructions from wscript to build the EDUCOPTER binary. 

Any Linux board can be ported to AruPilot by adding the necessary defintions in these files. The correct RC Input Protocol file should also be selected- the specific file shown in green is for SBUS input over UART.

## EDUCOPTER communication architecture



This diagram presents a **minimal working hardware configuration required to achieve stable quadcopter flight using ArduPilot on Linux**.

It highlights the communication links between:

- the Raspberry Pi flight computer
- the IMU (SPI)
- the barometer (I2C)
- the PWM driver (I2C)
- the GPS module (UART)
- the RC receiver (UART)

From researching other ArduPilot Linux platforms, these communication methods for each component are fairly standard, and calculations showed how using I2C for the IMU as well could potentially lead to data paackets being lost and therefore stability issues.

## EDUCOPTER as a research platform

Unlike commercial flight controllers, EDUCOPTER is intentionally designed as a **foundation for experimentation rather than a finished compact autopilot product**. EDUCOPTER builds from the research conducted by the OBAL project, and aims to include enough detail to fully replicate the design, as well as sharing information on custom Linux porting within ArduPilot.

The simplified base architecture allows future users to:

- increase hardware compactness through PCB redesign
- add functionality by including cameras or telemetry radios
- Apply these porting methods to other operating systems such as ChibiOS.

Because of this, EDUCOPTER can act as a starting point for students and researchers interested in exploring **custom ArduPilot flight controller development**.

# Future development opportunities

Several extensions could be explored to further develop the EDUCOPTER platform.

## LEDs and buzzer integration

One immediate improvement would be the integration of **status LEDs and a buzzer**, similar to those implemented in the OBAL board.

These components provide useful feedback during:

- boot status
- GPS lock acquisition
- calibration procedures
- arming conditions
- failsafe events

Adding these indicators would improve usability during setup and flight testing. They weren't included in this design due to the difficulty of implementation on a single-sided circuit board.

## Integrated power distribution

Another possible improvement would be integrating a **power distribution circuit directly into the EDUCOPTER PCB** in order to produce a more compact flight controller.

This approach was considered during development but was intentionally avoided in order to:

- reduce board complexity
- simplify manufacturing
- avoid routing high-current battery power on a single-sided PCB

Routing higher voltages across small PCB tracks introduces additional safety constraints, particularly when operating from a 4S LiPo supply. For this reason, integrated power distribution would likely be more appropriate for **smaller drone platforms operating at lower voltages**.

Future multi-layer PCB versions of EDUCOPTER could explore this direction further, reducing cost, weight and complexity of quadcopters.

## Additional sensor integration

The communication architecture used in this project allows straightforward integration of additional peripherals such as:

- cameras
- telemetry radios
- optical flow sensors

For example, integrating a camera would allow:

- live video transmission
- visual navigation experiments
- onboard autonomy research

Because ArduPilot already supports MAVLink-based interaction, these additions can be implemented directly without significant architectural changes and without the need for a companion computer.

## Real-time ESP32-based autopilot variants

A further research direction would be implementing a similar architecture using a **real-time microcontroller platform such as the ESP32 running a real-time operating system instead of Linux**.

Linux provides flexibility and accessibility for development, but it does not provide deterministic timing behaviour for control loops. Microcontroller-based systems running RTOS environments can achieve higher loop execution stability and are commonly used in dedicated flight controllers.

A comparable architectural structure to the Linux porting workflow shown in this repository can be found within:

- libraries/AP_HAL_ESP32
- libraries/AP_HAL_ChibiOS

Depending on the processor to be used.

## Summary

I hope you find this repository useful for future work tackling custom ArduPilot flight controllers. As a second reference page, the OBAL repository offers useful Linux support.

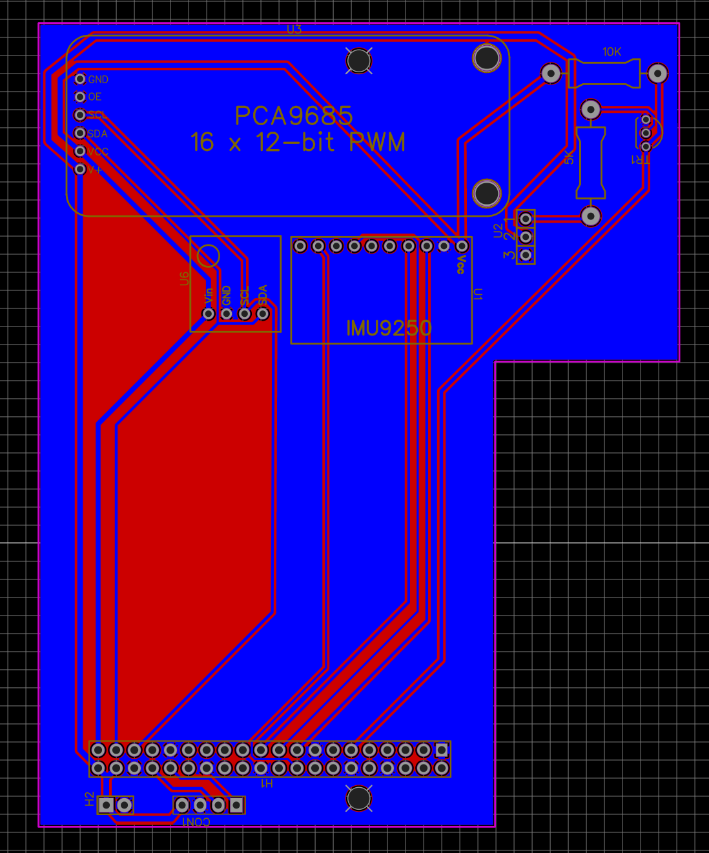
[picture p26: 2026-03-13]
hardware/images/EDUCOPTER_Bottom_Layer_PCB.png

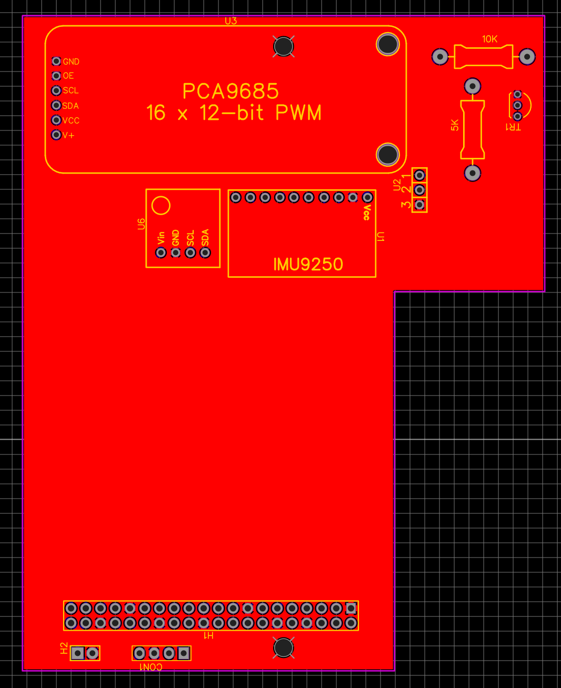
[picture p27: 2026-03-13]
hardware/images/EDUCOPTER_Top_layer_PCB.png

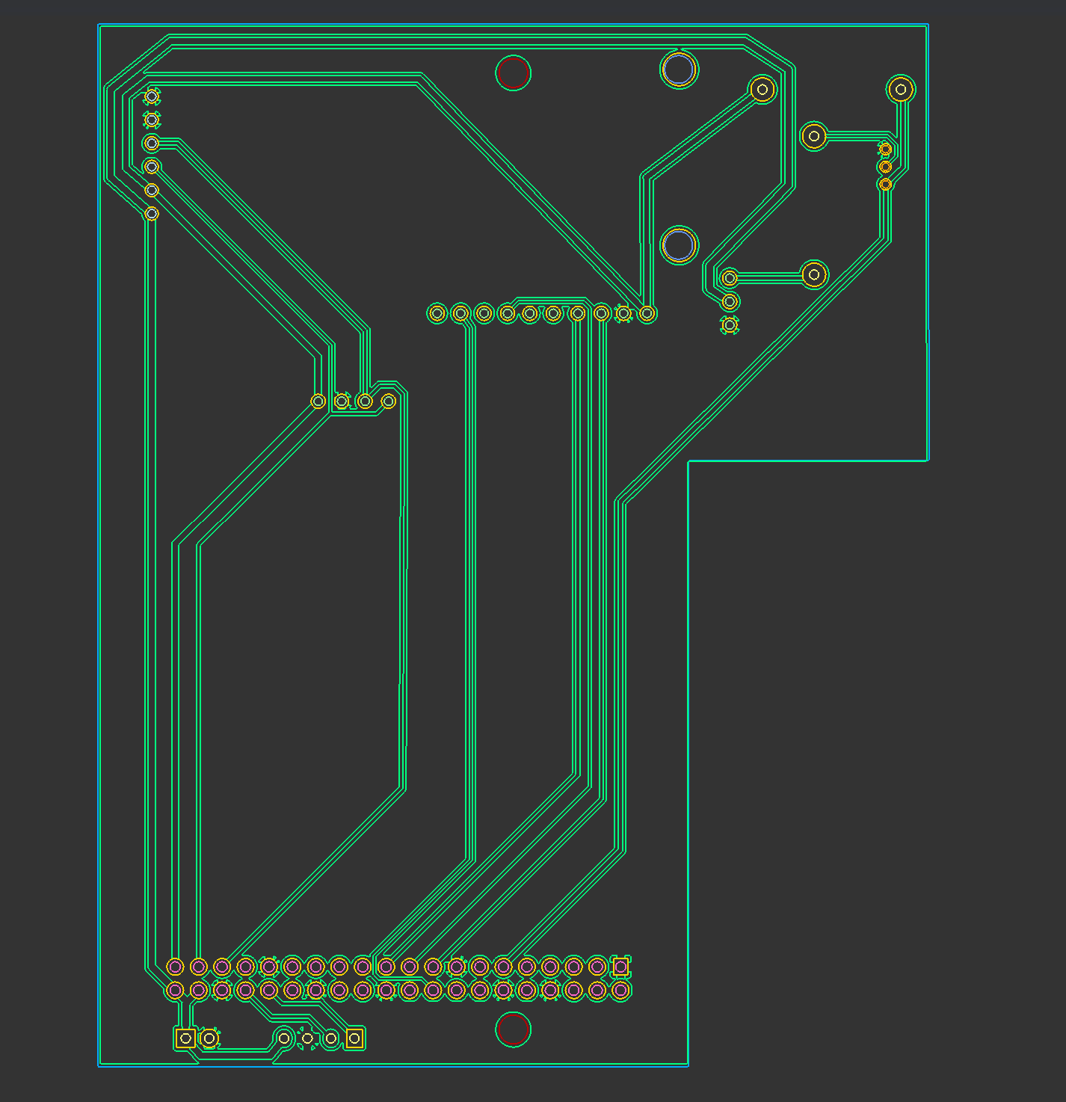
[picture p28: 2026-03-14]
hardware/images/gerber_view_bottomside.png

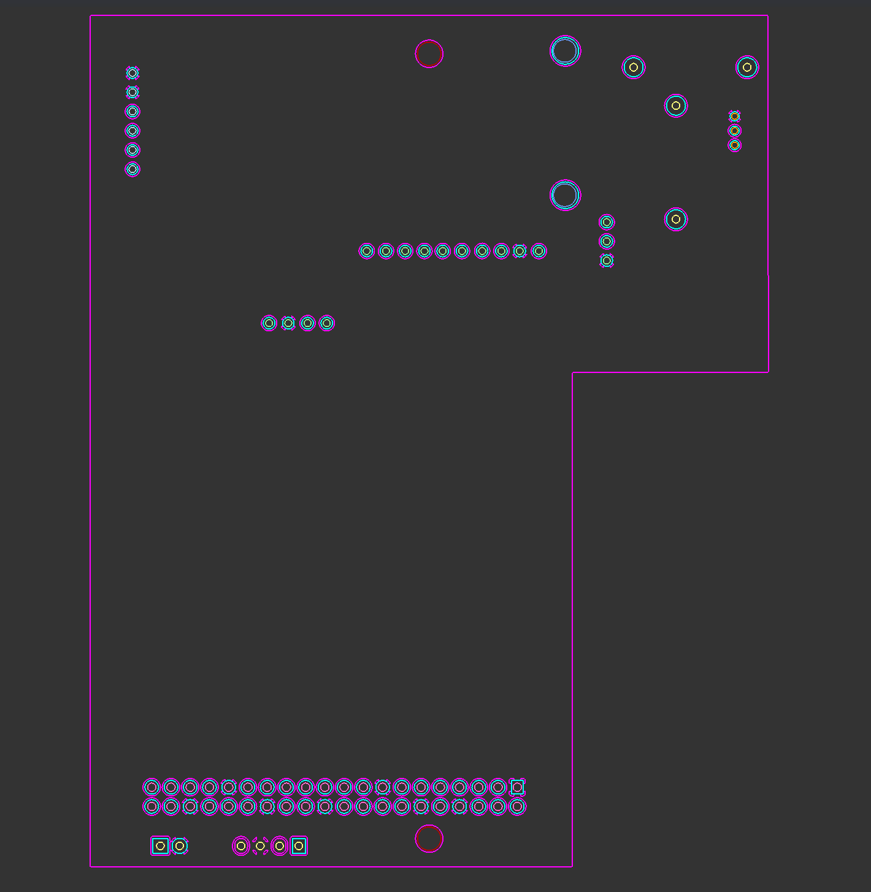
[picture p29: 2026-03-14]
hardware/images/gerber_view_topside.png

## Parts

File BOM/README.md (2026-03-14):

# Bill of Materials (BOM)

This Bill of Materials (BOM) provides a complete list of components used throughout the EDUCOPTER project. It includes parts required for both the EDUCOPTER Linux flight controller board and the final quadcopter platform used for testing and demonstration. As such, the list covers everything from electronic components on the flight controller (sensors, connectors, passive components, etc.) to the wider drone system, including items such as the frame, motors, ESCs, power distribution board, receiver, and GPS module. These external drone components are included primarily for completeness; builders do not need to select the exact same frame, motors, ESCs, or power distribution board listed here, and alternative compatible hardware may be used.

Some small electronic components (such as resistors, transistors, and Dupont cables) are commonly sold only in bulk quantities, which may not be ideal when sourcing parts individually. In educational environments or laboratories where basic electronics supplies are already available, it is recommended to use those existing components rather than purchasing large quantities unnecessarily. The notes column within the BOM indicates which parts are actually required in such cases.

This build assumes access to basic electronics assembly tools, specifically a soldering iron and solder, which are required for assembling the board and making electrical connections.

The custom EDUCOPTER circuit board itself is not included in the BOM. It is assumed that users will either order the PCB from a manufacturer using the provided design files, or produce the board themselves using a PCB milling machine (for example, the Makera Carvera).

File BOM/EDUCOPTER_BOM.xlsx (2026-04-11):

Item Number | Part Name | Description | Quantity | Unit Cost (£) | Supplier | Notes
Pi, Sensors and Actuators to solder to EDUCOPTER board
1 | Raspberry Pi 4 | The flight computer for the EDUCOPTER board | 1 | 38.09 | Raspberry Pi 4 8GB 4GB Computer Model B 1GB/2GB, quad-core Cortex-A72, BCM2711, 2.4 GHz and 5.0 GHz IEEE 802.11b/g/n/ac wireless - AliExpress 7 (https://www.aliexpress.com/item/1005007384599192.html) | The Raspberry Pi does not include built-in persistent storage. Instead, the operating system and files are stored on a microSD card inserted into the board. The Pi itself only contains RAM for temporary memory during operation. Therefore have at least a 16GB SD card to insert
2 | MPU9250 | Accelerometer, gyroscope and magnetometer | 1 | 8.38 | MPU-9250 9-Axis Sensor Module with Gyroscope, Accelerometer, Magnetometer - 16-bit Precision Motion Sensing & Orientation Detection for Robotics, Drones, and IoT Applications : Amazon.co.uk: Business, Industry & Science (https://www.amazon.co.uk/MPU-9250-gyroscopic-accelerator-precision-accelerometer/dp/B07VJ15M5N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) | Look out! You can find cheaper on sites such as Ali express but read reviews first. Some are fake and don't contain magnetometer which is an issue for this design #
3 | BMP280 | Barometer | 1 | 4.36 | Vidonergy 2Pcs GY-BME280-5V Barometric Sensor For Temperature/Humidity/Air Pressure | GY-BMP280-5V Digital Humidity Temperature Sensor Module(BMP280-5.0) : Amazon.co.uk: Business, Industry & Science (https://www.amazon.co.uk/Vidonergy-GY-BME280-5V-Barometric-Temperature-GY-BMP280-5V/dp/B0GCNNLZNF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) | Again, buy from anywhere but read reveiws first
4 | PCA9685 | PWM output driver to the ESCs | 1 | 5.99 | PCA9685 16 Channel 12-bit PWM Servo motor Driver I2C Module, Compatible with Arduino Raspberry Pi - Electrones : Amazon.co.uk: Business, Industry & Science (https://www.amazon.co.uk/Electrones-PCA9685-Channel-12-bit-Driver/dp/B0DVCH2BV2?hvadid=80333274973445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)
GPS and RC components to attach to EDUCOPTER board
5 | FOXEER M10Q 250 5883 | Compass GPS module | 1 | 15.49 | Foxeer M10Q 250 5883 Compass GPS Module – Unmanned Tech (https://www.unmannedtechshop.co.uk/products/foxeer-m10q-250-5883-compass-gps-module) | Any compass module with RX and TX pins can be used. But bear in mind GPS settings like baudrate in ardupilot.parm may need to be changed.
6 | FlySky FS-i6X 2.4GHz transmitter | Radio transmitter | 1 | 10.53 | aliexpress.com/p/tesla-landing/index.html?UTABTest=aliabtest128998_32160&src=bing&albch=shopping&acnt=135105396&albcp=555414207&albag=1299623965181476&slnk=&trgt=pla-2333026235593228&plac=&crea=81226557521530&netw=o&device=c&mtctp=e&utm_source=Bing&utm_medium=shopping&utm_campaign=PA_Bing_UK_PMAX_ALL_MAXV_purchase_AESupply_25.5.8&utm_content=PA_Bing_UK_PMAX_ALL_maxvalue_202505%2F8_newstore_purchase&utm_term=FlySky FS‑iA10B.&msclkid=6977c16f1d771a6bcc39a8da4fa1f027&aff_fcid=1cc255b207e2484ca58846188939ee10-1773490906378-09787-UneMJZVf&aff_fsk=UneMJZVf&aff_platform=aaf&sk=UneMJZVf&aff_trace_key=1cc255b207e2484ca58846188939ee10-1773490906378-09787-UneMJZVf&terminal_id=6d1937081b9a4e86bf789366d0502306&scenario=c_ppc_item_bridge&productId=1005005876493692&_immersiveMode=true&withMainCard=true&OLP=1123114608_f_group1&o_s_id=1123114608 | Any FS receiver or transmitter will work. But note that all support for this EDUCOPTER project is based around these specific receivers and transmitters
7 | FlySky FS iA-10B 2.4Ghz receiver | Radio receiver | 1 | 10.93 | Flysky 2.4G 10CH FS-iA10B 10 Channels Receiver FS IA10B for Transmitter FS-I10 FS-I6S FPV RC Helicopter Quadcopter Aircraft - AliExpress 26 (https://www.aliexpress.com/item/1005003879270035.html)
Pin headers, resistors, transistors and JR cables to connect components
8 | Glarks 112Pcs 2.54mm Male and Female Pin Connector Assortment Kit | Male and Female 2.54mm pin headers | 1 | 10.95 | Glarks 112Pcs 2.54mm Male and Female Pin Connector Assortment Kit, 100pcs Stackable Shield and 12pcs Breakaway PCB Board Pin Header for Arduino Prototype Shield : Amazon.co.uk: Business, Industry & Science (https://www.amazon.co.uk/Glarks-Connector-Assortment-Stackable-Breakaway/dp/B07CWSXY7P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) | Whats needed from this kit: 1 2x20 female, 1 1x4 female, 1 1x10 female, 1 1x6 female, 1 1x2 male, 1 1x4 male, 1 1x3 male,
9 | 40 Pin Dupont Line 10CM 20CM 30CM 40CM Male to Female/Male to Male/Female to Female Jumper Wire | Female-Female dupont connector cables | 1 | 0.29 | 40 Pin Dupont Line 10CM 20CM 30CM 40CM Male to Female/Male to Male/Female to Female Jumper Wire Dupont Cable for Arduino - AliExpress (https://www.aliexpress.com/item/1005002039605899.html?curPageLogUid=yOB5bkJgImz6) | Whats needed from this kit: 3 female-female headers
10 | 600 Pcs Metal Film Resistor Kit | 5k and 10k ohm resistors | 1 | 1.99 | 600 Pcs Metal Film Resistor Kit Assorted Kit 30 Values Metal Film Resistor Resistance 1/4W 1ohm-10Mohm 1% Tolerance - AliExpress (https://www.aliexpress.com/item/1005006706508149.html?curPageLogUid=5HNpMamxhSvY) | Only need 1 5K resistor, 1 10k resistor
11 | 50-900PCS Transistors kit NPN PNP | NPN SBUS transistor | 1 | 1.21 | 50-900PCS Transistors kit NPN PNP S8050 S8550 S9012 2N3904 2N3906 C1815 A1015 MJE13001 BC327 BC337 BC517 BC547 BC548 BC549 BC558 - AliExpress (https://www.aliexpress.com/item/1005006208531017.html?curPageLogUid=mXJuVvJn5tXy) | Only need 1 2N3904 NPN resistor
Drone frame, motors and ESCs
12 | F450 drone frame | Quadcopter drone frame | 1 | 2.14 | aliexpress.com/p/tesla-landing/index.html?UTABTest=aliabtest128998_32160&src=bing&albch=shopping&acnt=135105396&albcp=555414207&albag=1299623965181476&slnk=&trgt=pla-2333026235593228&plac=&crea=81226557521530&netw=o&device=c&mtctp=e&utm_source=Bing&utm_medium=shopping&utm_campaign=PA_Bing_UK_PMAX_ALL_MAXV_purchase_AESupply_25.5.8&utm_content=PA_Bing_UK_PMAX_ALL_maxvalue_202505%2F8_newstore_purchase&utm_term=drone frame&msclkid=378c0269a59119caacf36bdcd43dd4a3&aff_fcid=3981e43cd6094356b7b3b4a80fa528bd-1773498799849-07603-UneMJZVf&aff_fsk=UneMJZVf&aff_platform=aaf&sk=UneMJZVf&aff_trace_key=3981e43cd6094356b7b3b4a80fa528bd-1773498799849-07603-UneMJZVf&terminal_id=6d1937081b9a4e86bf789366d0502306&scenario=c_ppc_item_bridge&productId=1005010273741831&_immersiveMode=true&withMainCard=true&OLP=1123114608_f_group1&o_s_id=1123114608
13 | 40A Brushless ESC with XT60 Connector Brushless Motor Electric Speed Controller | Electronic Speed Converters | 4 | 13.28 | https://www.amazon.co.uk/Brushless-Controller-Helicopter-Installation-Enthusiasts/dp/B0GFSMPF5Z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 | Any ESCs over 20A are fine, but I would recommend buying ones with the output to motor cables already attached to save time
14 | Brushless Motor 2213 935KV | Motors | 1 | 54.99 | HAWK'S WORK Brushless Motor 2213 935KV, 2-4S Motor for RC Plane Multi Copter DIY Done 450 F550 S500 S550 X525 DJI Phantom Quadcopter (Emax MT2213 CW*2+CCW*2) : Amazon.co.uk: Toys & Games (https://www.amazon.co.uk/HAWKS-WORK-Brushless-Multirotor-Airplane/dp/B0B214VDZG?adgrpid=1185274433616236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) | Motors designed for a 4S battery are fine (rated volatge 14.8V-16V) if using a 4S motor
15 | Holybro S500 V2 Kit/ X500 Kit Replacement 1045 10X4.5 10inch | Propellors | 1 | 11.69 | Holybro S500 V2 Kit/ X500 Kit Replacement 1045 10X4.5 10inch Self-locking Propeller CW CCW for RC Multirotor Airplane DIY Parts - AliExpress (https://www.aliexpress.com/item/1005008948450964.html?curPageLogUid=gvywfwRFGG6u) | Any propellors fine, 10 inch worked well for this project
16 | SIGP 4S Lipo Battery 5000mAh | 4S 5000mAh Battery | 1 | 40.49 | SIGP 4S Lipo Battery 5000mAh 6000mAh for 14.8V 70C 100C with EC5 XT90 with RC Car VehiclesAirplane Drone FPV Racing Hobby - AliExpress (https://www.aliexpress.com/item/1005007472070554.html?curPageLogUid=0ULIOYWxfpZe)
Power Distribution
17 | Holybro Power Distribution Board (PDB) XT30 | Distribution board | 1 | 10.87 | Holybro Power Distribution Board (PDB) XT30 pre-soldered for PM02 PM02D PM03 PM06 PM07 Power Module X500 V2 FPV Drone Parts - AliExpress (https://www.aliexpress.com/item/1005005833911450.html?curPageLogUid=hemdBGgqsSuv)
18 | RUNCCI-YUN 10 Pair XT30U (XT30 Upgrade) Male Female Bullet Connectors Power Plugs | XT30 connectors | 1 | 5.99 | RUNCCI-YUN 10 Pair XT30U (XT30 Upgrade) Male Female Bullet Connectors Power Plugs with Heat Shrink for RC Lipo Battery : Amazon.co.uk: Toys & Games (https://www.amazon.co.uk/RUNCCI-Upgrade-Female-Connectors-Battery/dp/B07PC1YKVW?s=kids) | This is to be attached to the end of the ESCs so they can connect to the power distribution board
19 | XT30 JST T plug to USB DC Buck Converter | DC-DC converter for USBA | 1 | 3.47 | XT60 XT30 JST T plug to USB DC Buck Converter In 5.5*2.1 5.5*2.5 9V 12V 24V 40V To 5V USB Step Down Power Supply Module Out USB - AliExpress 13 (https://www.aliexpress.com/item/1005004803386998.html?) | This will connect to the end of the power distribution board and will be the output to power the EDUCOPTER board through the Raspberry Pi usbc port
20 | Essager 3A USB Type C Cable USB A To Type C | USBA to USBC adapter | 1 | 0.76 | Essager 3A USB Type C Cable USB A To Type C Fast Charging Cables For iPone 15 Samsung Xiaomi Mobile Phone Data Charger Wire Cord - AliExpress (https://www.aliexpress.com/item/1005007504310983.html?curPageLogUid=yhdUjF4n6vdC) | USBC adapter for the Pi

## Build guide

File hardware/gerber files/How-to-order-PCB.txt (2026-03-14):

How to Order PCB

Please refer to:
https://docs.easyeda.com/en/PCB/Order-PCB

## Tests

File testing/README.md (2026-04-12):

## Testing the board for I2C and SPI detection, and UART verification ##

When porting a new board to ArduPilot, several changes are required in the Linux HAL source code. As a result, configuration mistakes are common and can be difficult to diagnose. This section provides a systematic hardware verification procedure to rule out wiring faults or configuration errors before debugging the software.

---

##  Hardware Verification ##

The first step in troubleshooting is to verify the hardware functionality and wiring. This can be done by checking whether the Raspberry Pi detects the barometer, IMU, PCA9685 PWM driver, RC receiver and GPS module.

## 1. I2C device tests ##

The two devices connected via I2C are the PCA9685 and the BMP280 barometer. They can be detected on the I2C bus using the i2c-tools package:

`sudo apt update`

`sudo apt install i2c-tools`

Then check that i2c exists by running the following command:

`ls /dev/i2c*`

This should return /dev/i2c-1. If the terminal replies with nothing, this is most likely due to I2C not being enabled. Follow step X in the software README file to enable I2C.

The I2C devices can then be detected using:

`sudo i2cdetect -y 1`

This should show two devices on the I2C bus as in the image below. The BMP280 should be on the 0x76 address and the PCA9685 on the 0x40.

If these devices do not appear during the I2C scan, this may be due to several hardware or wiring issues:

| Problem | Solution |
|---|---|
| Devices are not the expected model (e.g. BMP180 instead of BMP280) | Verify the exact sensor part number printed on the module. Some breakout boards look similar but use different I2C addresses and drivers. |
| Components are not receiving power | Check for solder bridges or damaged PCB traces. Use a digital multimeter to confirm ~3.3 V between Vcc and GND on each device. |
| Components are faulty | Replace the device or test with a known working module to confirm whether the sensor is damaged. |

## 2. SPI device tests ##

Detecting SPI devices on a Raspberry Pi 4 is different from I2C. There is no equivalent to i2cdetect for SPI because SPI devices do not have addresses. 

First, confirm that the SPI interface exists:

`ls /dev/spidev*`

If this returns nothing, follow the same step X in the software section and return to this point.

Next, install the SPI testing tool:

`sudo apt update`

`sudo apt install python3-spidev`

Run the following in your terminal:

`python3 - <<EOF
import spidev
spi = spidev.SpiDev()
spi.open(0,0)
spi.max_speed_hz = 1000000
print(hex(spi.xfer2([0x75 | 0x80, 0x00])[1]))
EOF`

The expected output is 0x71 for an IMU9250. If the device does not appear during the I2C scan, this may be due to several hardware or wiring issues:

| Problem | Solution |
|---|---|
| Device is not the expected model eg GY91 | Verify the exact sensor part number printed on the module. |
| Component is not receiving power | Check for solder bridges or damaged PCB traces. Use a digital multimeter to confirm ~3.3 V between Vcc and GND on each device. |
| The CS pin isn't connected (common when porting your own board) | Make sure to redesign the PCB with the CS pin connected to CS0 or CS1 of the Pi |
| Component is faulty | Replace the device or test with a known working module to confirm whether the sensor is damaged. |

N.B. In regards to the chip select pin, it was found that any connection error with the IMU resulted in ArduPilot refusing to connect with MAVProxy over network connection. If you are experiencing this issue, this could be the problem.

## 3. UART device tests ##

## A. RC Receiver ##

The RC receiver transmits using SBUS protocol which is inverted by the EDUCOPTER board. The inversion can be tested using an oscilloscope and connecting both contacts with the input and output of the inversion circuit. The results should show a waveform like in the image below:

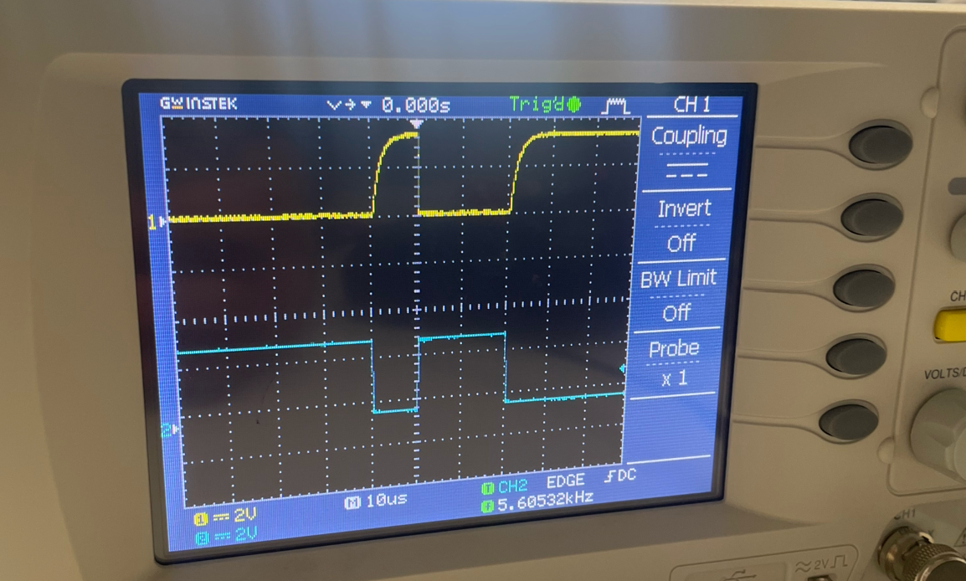
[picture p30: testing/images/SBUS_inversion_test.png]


Bytes verification can then be conducted. First, confirm the correct uart ports are enabled:

`ls /dev/ttyAMA*`

ttyAMA0 for the GPS and ttyAMA3 for the RC receiver should appear. 

Next, turn on the RC transmitter (the controller) and connect to the receiver using the standard connection protocol. For the FlySkyiA10B used in this project, a bidnig plug is used for this process. Folow the instructions on FlySky's website or using youtube.

Then scan for SBUS bytes:

`sudo hexdump -C /dev/ttyAMA3`

The expected output is shown in the image below:

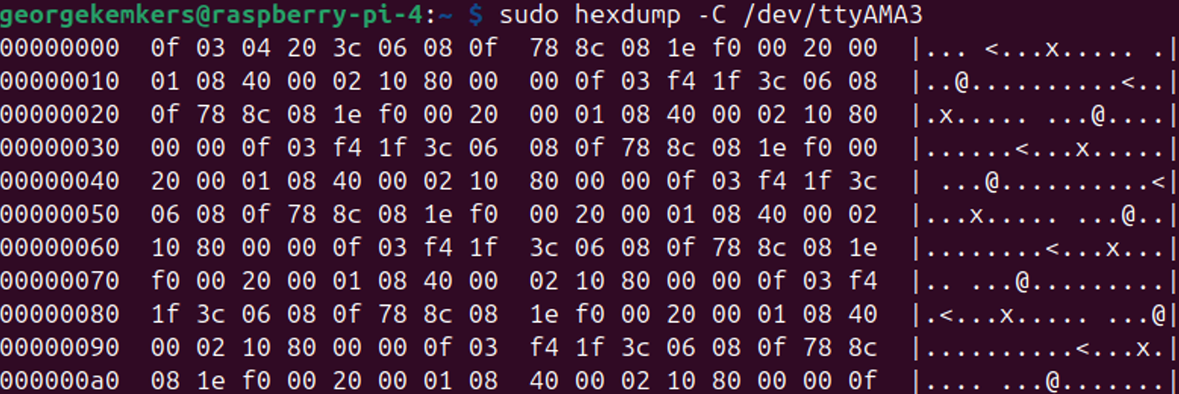
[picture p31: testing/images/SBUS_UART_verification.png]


If this doesn't appear AND the circuit has already been tested using thge oscilliscope, the issues could be:

| Problem | Solution |
|---|---|
| The receiver isn't configured for SBUS (very common) | Follow the manual for your particular receiver and transmiitter pair to set up SBUS |
| Component is not receiving power | Check for light from the receiver. The FS iA10B trasnmits a solid red light when binded |
| Component is faulty | Replace the device or test with a known working module to confirm whether the receiver is damaged. |

## B. GPS module ##

A similar process of detecting UART input bytes can be done with the GPS module. Follow the steps described previously but instead use this command:

`sudo hexdump -C /dev/ttyAMA0`

This project found that when the GPS module was not connected to satellites, this method of testing could appear unreliable (where the GPS sometimes outputted nothing to terminal). The main isses with GPS moudles were found in ardupilot.parm, which will be discussed next.

---

## Software verification

If the previous steps were completed successfully for all components, hardware and wiring issues can largely be ruled out. Any remaining problems are therefore likely to originate from the EDUCOPTER binary configuration or the `ardupilot.service` and `ardupilot.parm` files.

There are many ways in which a Linux board can be incorrectly ported in ArduPilot, so it is not possible to cover every issue here. However, several recommendations are provided below based on experience gained during this project.

---

## 1. Use `grep` to inspect existing Linux board builds

To see examples of how other Linux boards define their hardware configuration, use the `grep` command to search the ArduPilot source tree for existing Raspberry Pi–based boards such as Navio2 and OBAL.

For example:

`grep -rn "_OBAL" ~/ardupilot/libraries/`

`grep -rn "NAVIO2" ~/ardupilot/libraries/`

These commands identify the files in which these board definitions appear and help locate the relevant configurations used during compilation.

Reviewing these examples can provide guidance when defining new board subtypes in the Linux HAL.

You can also refer to the ArduPilot architecture diagram located in the **Future Research** folder to identify which files are commonly modified during board porting.

---

## 2. Inspect board definitions in the ArduPilot GitHub repository

Another useful debugging approach is to browse the ArduPilot GitHub repository directly and examine how existing Linux boards are implemented.

Navigate to the relevant files and search for board subtype definitions and `#if` preprocessor directives to understand how these configurations are applied during compilation. This helps identify where hardware-specific logic is selected when building the vehicle firmware binary.

## 3. Check the `.service` and `.parm` files

These files are responsible for configuring how ArduPilot accesses UART devices on the Raspberry Pi.

For the EDUCOPTER build, the GPS configuration was handled primarily through these files, as is common with many ArduPilot Linux builds. The `ardupilot.service` file maps ArduPilot SERIAL ports to physical Raspberry Pi serial devices, so it is important to ensure that the correct serial interfaces are used.

Things to check:

1. GPS protocol is set correctly:

   `SERIAL3_PROTOCOL = 5`

   This enables the GPS driver on SERIAL3.

2. The correct baud rate is configured:

   `SERIAL3_BAUD = 115`

   The GPS module used in this project operates at 115200 baud. Other modules may require a different baud rate, so consult the module documentation if communication fails.

3. GPS auto-detection is enabled:

   `GPS_TYPE = 1`

   This allows ArduPilot to automatically detect the connected GPS module.

---

## Final advice

If errors persist after following these steps, consider reaching out to the ArduPilot community through the ArduPilot Discord server or the ArduPilot Discuss forum. The community is active and very supportive of new hardware porting efforts.

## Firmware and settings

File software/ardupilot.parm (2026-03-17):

FRAME_CLASS 1
FRAME_TYPE 1

SERIAL0_PROTOCOL -1
SERIAL2_PROTOCOL -1
SERIAL5_PROTOCOL -1

# MAVLink telemetry for MAVProxy / Mission Planner
# SERIAL1 is mapped to UDP port 14550 in ardupilot.service
# MAVLink2 protocol
SERIAL1_PROTOCOL 2
SERIAL1_BAUD 115

# GPS on GPIO5 with 115200 baudrate and auto (1) GPS detection 
SERIAL3_PROTOCOL 5
SERIAL3_BAUD 115
GPS_TYPE 1

LOG_BACKEND_TYPE 1
LOG_DISARMED 1

BRD_SAFETYENABLE 0
ARMING_CHECK 0

SERVO1_FUNCTION 33
SERVO2_FUNCTION 34
SERVO3_FUNCTION 35
SERVO4_FUNCTION 36
